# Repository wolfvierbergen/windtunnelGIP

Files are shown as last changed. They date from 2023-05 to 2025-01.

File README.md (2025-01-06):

# Open Wind Tunnel Design and Construction

An experimental project to design, build and test a functional open wind tunnel for aerodynamic testing and research.

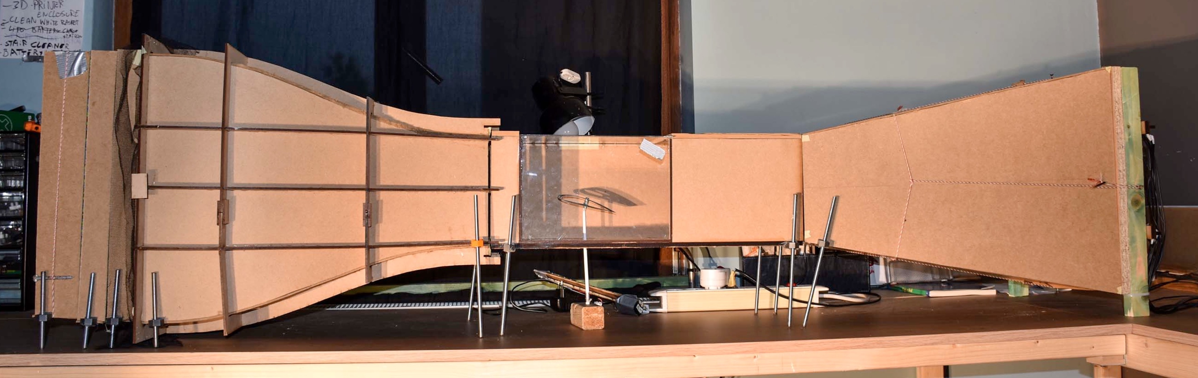
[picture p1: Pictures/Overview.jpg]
Complete Wind Tunnel

*The complete assembled wind tunnel*

**Read the original paper in [dutch](https://github.com/wolfvierbergen/windtunnelGIP/blob/main/eindwerk%20finale%20versie.pdf?raw=true) or the [translated version](https://raw.githubusercontent.com/wolfvierbergen/windtunnelGIP/refs/heads/main/Thesis%20final%20version%20Dutch%20to%20English%20by%20Google%20Translate.pdf)*** <br>
More pictures can be found in the [presentation](https://raw.githubusercontent.com/wolfvierbergen/windtunnelGIP/refs/heads/main/Presentations/Presentatie%20windtunnel%201.2.pdf)<br>

<sub><sup>*Translation is done by Google Translate and contains errors.</sup></sub>
### Key Features

- Open-circuit design with 5.09:1 contraction ratio
- Maximum air speed of 33 km/h (9.2 m/s)
- Laminar flow generation capabilities
- Transparent test section for flow visualization
- Digital speed control system

## Technical Design

The wind tunnel consists of six main components. From left to right:

### 1. Honeycomb Flow Straightener
- 6600 plastic straws arranged in a grid
- 6mm diameter, 60mm length
- Mounted at tunnel inlet
- Reduces **lateral turbulence**

### 2. Flow Conditioning Screens
- Two screens with 64% open area
- Nylon mesh construction
- 45mm spacing between screens
- Reduces **axial turbulence**

### 3. Contraction Section
- 5.09:1 contraction ratio
- Fifth-order polynomial curve profile
- Optimized for minimal flow separation
- MDF construction with external skeleton

### 4. Test Section
- Dimensions: 180mm × 190mm × 580mm
- Plexiglass windows for visualization
- Bottom access port for force measurements

### 5. Diffuser
- 9.9° expansion angle
- 574mm length
- Gradual velocity reduction
- Pressure recovery section

### 6. Drive System
- 4 × 210W brushless motors
- Three-blade propellers
- Electronic speed controllers
- Servo tester for power control
- 7.4V LiPo battery power source

## Experimental Results

### Airfoil Testing
Conducted comprehensive testing using NACA 4412 airfoil:
- Lift coefficient measurements
- Angle of attack comparison
- Speed dependency analysis

Key findings:
1. Maximum lift achieved at 30° angle of attack
2. Experimental results closely matched theoretical predictions

## Technologies Used

- Fusion 360 for CAD design
- Laser cutting for precision components
- 3D printing for custom parts
- Pitot tube airspeed measurement
- Digital force measurement system

## Testing Methods

1. **Air Speed Measurement**
   - Pitot tube system
   - Fluid manometer measurement
   - Multiple test points across section
   - Speed range: 0-33 km/h

2. **Flow Quality Assessment**
   - Smoke visualization
   - Flow uniformity testing

3. **Force Measurement**
   - Digital scale
   - Multiple angle testing

## Contributors

- Maarten Espeel
- Kobe Vlasselaer
- Wolf Vierbergen

## Acknowledgments

Special thanks to:
- Ludo Verluyten (Mentor)
- Bike Valley Team
- Heilig-Hartinstituut Heverlee 

---

**Note**: For detailed technical specifications, experimental procedures, and complete results, please refer to the full thesis document.

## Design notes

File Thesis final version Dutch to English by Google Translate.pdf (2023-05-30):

Sacred Heart Institute
third degree
355 Naamsesteenweg
3001 HEVERLEE

# Wind tunnel

# Design and construction of an open wind tunnel

### Martin Espel

Wolf Vierbergen
Kobe Vlasselaer

### 6 Technology-Sciences

## GIP

School year 2019-2020

Translated from Dutch to English - www.onlinedoctranslator.com (https://www.onlinedoctranslator.com/en/)

Sacred Heart Institute
third degree
355 Naamsesteenweg
3001 HEVERLEE

# Wind tunnel

# Design and construction of an open wind tunnel

### Martin Espel

Wolf Vierbergen
Kobe Vlasselaer

### 6 Technology-Sciences

## GIP

School year 2019-2020
3

4

PREFACE

This integrated test is about designing, building and testing a wind tunnel. This paper was written within the framework of the GIP of 6 TW in the Sacred Heart Institute Heverlee. We worked on this paper from September to April.
Together with our mentor, Ludo Verluyten, we formulated the research questions. Construction was slow in the beginning due to problems with ordering the parts, but it has been nicely finished. In this way we were also able to answer the research question. While writing, we could always ask our mentor, Ludo Verluyten, our questions so that we could continue smoothly.

We would like to thank our mentor for always supporting us in recent months. In addition, our Dutch teacher for improving each version. We would also like to thank Harm Ubbens for his tips and feedback and especially for helping where necessary at the beginning of the research. Without this help, this research would not have been possible.

We would also like to thank all the friends and family who supported us mentally and financially during the design, build, testing and writing of this paper. Thanks to them we can successfully close this investigation.
We wish you a pleasant reading experience.
Kobe Vlasselaer
Martin Espel
Wolf Vierbergen

Leuven, February 2020

5

6

Contents

4
5
6
7

7

INTRODUCTION

Our integrated test (plaster) is about wind tunnels. We absolutely wanted to make our plaster on aerodynamics. We think it is a pity that aerodynamics is not part of the curriculum of secondary education and that is why we wanted to base our plaster on it.
The aim of our plaster is to build a wind tunnel that works so that we can do tests on it. We want to prove that it is possible to generate laminar power with our self-built wind tunnel. It was a long project with many setbacks and additional problems that we did not expect.
Our integrated test also includes an experimental part: we did tests in our wind tunnel and tried to find the optimal angle and shape for a wing so that it experiences as little air resistance as possible.
We looked for our information on the internet and we also visited Bike Valley. They have built a wind tunnel to test the attributes of cycling (kits, shape of bicycle and helmets) so that the cyclist suffers as little as possible from air resistance. There they gave us many tips for the shape and materials of our wind tunnel.

For us it was a very interesting and instructive experience to build a wind tunnel and we hope that you will have an instructive and enjoyable experience reading our integrated test.

8

## 1 literature study

### Aerodynamics

Aerodynamics is the science that describes the movement of gases and liquids. It is part of the field of fluid mechanics. Describing the flow behavior of a liquid or gas can relate to flow in free space or to a body such as an aircraft wing [4].

### History of Aerodynamics

The science of aerodynamics has only existed since the 17th century. Before that, however, people had already used the wind for a long time, such as in a sailing boat and a windmill.

The first person to develop a theory of air resistance was Isaac Newton. He was followed by Daniel Bernoulli, who found a relationship between pressure, density and flow velocity in an incompressible flow. After that, knowledge about aerodynamics progressed at a rapid pace thanks to contributions from Leonhard Euler and Sir George Cayley, among others.

In the early 18th century, Benjamin Robins began measuring air resistance with a whirling arm. Frank H. Wenham also experimented with this, but the results were not satisfactory. This is how the idea of a wind tunnel came about. In 1871 the first wind tunnel was built by the Briton Francis Herbert Wenham, allowing accurate measurements of aerodynamic forces. The experiments he performed were related to lift and drag [17]. A replica of this first wind tunnel can be found in figure 1.

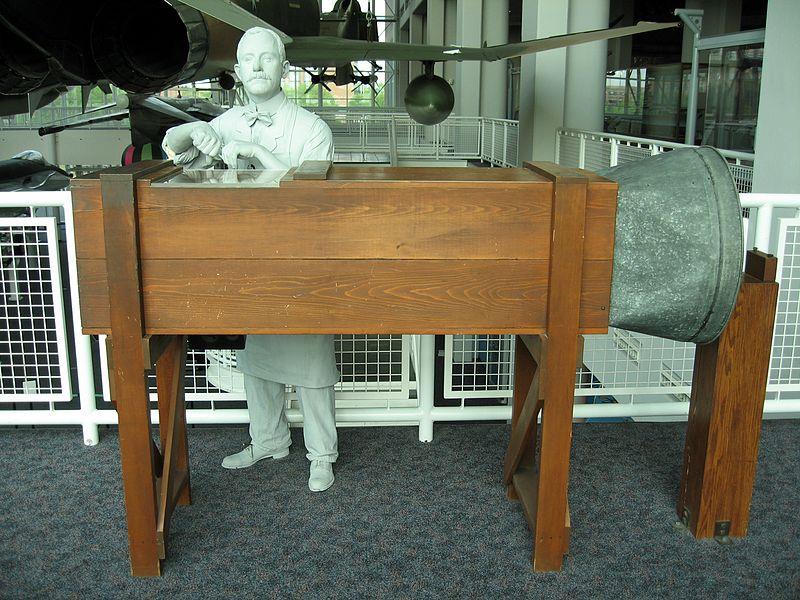
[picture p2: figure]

Figure 1: Replica of the first wind tunnel
German Otto Liliental was the first person to fly in a glider. He succeeded with a new design of the wings, which had a thin and curved airfoil so that they would produce high lift and low drag. Thanks to Liliental's new wings and their own research in their wind tunnel, the Wright brothers made their first successful flight in a powered aircraft on December 17, 1903. [4]

9

### Importance of an aerodynamic object

Air is a matter that exerts a force on an object when it flows past it. During the process, the air sticks to the object a bit, which we call air resistance. For an object that is as aerodynamic as possible, the air resistance must be minimal. The wind therefore sticks a bit on the object, but that does not happen a little above the object. So there is a difference in speed between the air that hits the object (lower airflow) and the air that flows a little above it (upper airflow). This creates a boundary layer between the two different air flows. If the lower airstream separates from the object and collides with the upper airstream, turbulent flow is created. Due to the collision, the wind particles form a swirling trajectory, which causes a lot of air resistance.

In order to obtain an object that is as aerodynamic as possible, it is therefore necessary to ensure that the airflow sticks to the object and does not come loose from it or as little as possible. So one tries to avoid corners and to obtain a nice smooth layer. [19]

### Determination Laminar or turbulent flow

Osbourne Reynolds defined the Reynolds number in 1883. He was an Irish physicist who was mainly concerned with hydraulics and hydrodynamics.
The Reynolds number is a dimensionless quantity used to determine whether a flow is laminar or turbulent. A dimensionless number means that the number has no unit. The number can be calculated using the following formula:

=

Whereby: - =the density in kg/m3• v = the speed in m/s. D = characteristic length in m. µ = the dynamic viscosity expressed in kg/ms

If the Reynolds number has a low value, you have laminar flow, and if the value is high, the flow is turbulent. For example, with flow in tubes you have laminar flow if the Reynolds number has a value below 2300 and you have turbulent flow if the Reynolds number has a value above 3500. If the number has a value between 2300 and 3500, it depends of various factors such as wall roughness whether you have turbulent or laminar flow. [8, 25 & 37]

### Bernoulli's law

Daniel Bernoulli was a Swiss physicist who lived in the 18th century. In 1725 he moved to Saint Petersburg in Russia where he went to study at the newly founded academy. There he met Leonard Euler with whom he would later work closely. Bernoulli's law describes the flow behavior of gases and liquids and gives a

10 explanation of the pressure change with altitude and speed changes. For example, he writes that the faster a gas or liquid passes an object, the lower the pressure on that object will be. Of course, the law also works the other way around, ie the slower a liquid or gas passes through an object, the greater the pressure on that object will be [34, 7]. Bernoulli derived a formula that uses the law of conservation of energy. The sum of the kinetic energy density (dynamic pressure), the gravitational pressure and the pressure equals a constant.

1
2
- 2+ -gh + p = constant

Of - =the density (kg/m3) v = the speed (m/s) g = the acceleration of gravity (m/s2 ) h = the height difference (m) p = the pressure (Pa)

Bernoulli's law applies under a number of conditions. These are the following:
1. Density is constant. The fabric must therefore not be compressed or stretched anywhere.
2. The fabric must not have internal friction. The viscosity should be zero.
3. The flow is stationary (= constant speed).

### Application: Aircraft operation

Like every object on our earth, an airplane is attracted by gravity. In order to put an aircraft in the air, forces that counteract gravity must therefore be exerted. This force, which must ensure that an aircraft does not fall down, is also referred to as 'the lift'. This acting lift force must be greater than gravity and in the opposite direction.

In addition, an aircraft must be able to move in the air. Here too, the aircraft encounters an opposing force, namely the resistance of the air. In order to move in the air, the aircraft must therefore perform extra work, which is provided by the aircraft's engines.

Figure 2 illustrates the action of the various forces.

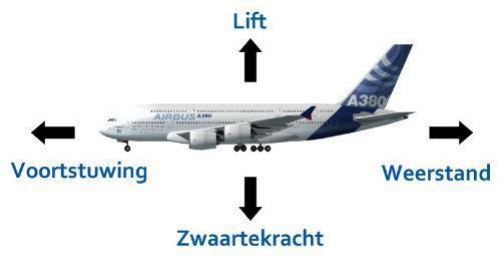
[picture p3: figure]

Figure 2: Forces on an aircraft

11

### Propulsion

In order for an aircraft to propel in the air, it must exert forward thrust. There are two types of engines that can produce this thrust, propeller-driven or jet-powered engines.

In a propeller drive, a rotational movement of a propeller or airscrew is caused by a motor. The propeller rotates in the air and this creates a pressure difference at the front and rear of the propeller blades, creating a forward force. This force pushes the plane forward.

In jet propulsion, air is sucked into the front of a jet engine and then compressed by a compressor. The air is mixed with the fuel and when burned creates a large amount of heat. These heated gases will expand strongly at the rear as they leave the engine. The associated pressure differences cause the propulsive force. The propulsive force generated by the engine must be at least as great as the drag force of the air.

### Resistance

When an object moves forward in the air, this object experiences a resistance from the air particles that opposes the forward movement. This aerodynamic force is a force caused by the object's interaction with the air. Air has a certain viscosity and will, as it were, stick to the object. This creates a speed difference between the air above the surface of the object and the air adjacent to the object. This causes a variation in flow. A laminar flow that offers little resistance can turn into a turbulent flow in which the air particles make rotational movements that increase the resistance. In addition, the air particles have a hard time moving along a sharp angle. A void is then created behind the block with turbulent flows that offer a lot of resistance,

Figure 3: turbulent flow at a block [39]

These turbulent flows must be avoided as much as possible because this means that the aircraft will have to develop more power to move forward. To reduce these turbulent flows, it will be necessary to ensure that the aircraft and wings adopt a shape that is more 'aerodynamic'. Among other things, sharp corners on the aircraft must be avoided. Scientists have been able to show that a wing/aircraft that has a teardrop shape will give the best results [19]. With this teardrop shape, the wing is rounded at the front and ends in a point at the back. This way the laminar flow is maintained as shown in figure no. 4. The droplet as shown in figure 4 is the most aerodynamic.

12

Figure 4: Currents along a drop shape (27)

In addition, the air molecules create a frictional force on the aircraft. It has been shown that when the surface of the aircraft is smooth, there is less friction than with a rough surface [19].

Elevator
To obtain lift in an aircraft, the upward force must be greater than the downward gravitational force, because according to Newton's second law, an object can only lift if the sum of all the forces acting on that object produces a net upward force. Several theories have been described to explain aircraft lift and some theories are more accepted than others. It is always important that lift can only be obtained when a fluid such as air is present, causing the wing to collide with the air molecules when the aircraft is moving forward.
In a first theory, Bernoulli's law is applied. The lift is generated by the specific asymmetric curvature of the wing which causes the flow to flow faster on top of the wing than under the wing. Because of the shape of the wing, the airflow will travel a greater distance at the top than at the bottom. This means that the air has to move faster from above over the wing. These airspeed differences are converted into pressure differences via Bernoulli's law. The greater the speed of the air, the lower the pressure (see Figure 5) [21].

Figure 5: Pressure differences on a wing [21]

This means that the air pressure at the bottom of the wing is higher than at the top. These pressure differences therefore provide a vertical lift force upwards. This theory can be found in many textbooks, but this theory is not entirely correct. According to this theory, in order to gain lift, the wing must have an asymmetrical shape in which the air above the wing travels a longer distance than at the bottom of the wing. However, it has been shown that lift can also be created with wings with a symmetrical shape. In addition, planes can sometimes be seen flying upside down in aircraft shows. The air molecules will then become one

13 travel longer distance at the bottom compared to the top. These aircraft also remain suspended in the air and thus receive a lifting force upwards [26]
Another and currently more accepted explanation for lift force is the fact that due to the shape and angle a wing makes, the air will move in a downward direction. Due to Newton's second law, this will create a downward force on the air. This downward force then causes an upward upward force according to Newton's third law (action and reaction). So the wing exerts a downward force on the air and the air therefore exerts an upward force on the wing as shown in Figure 6.

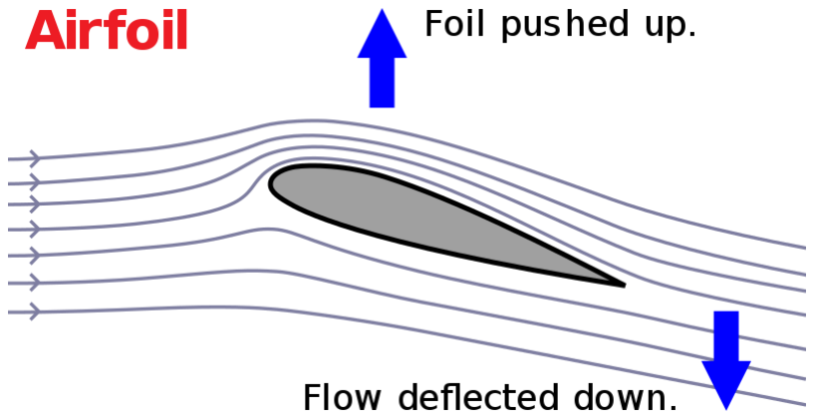
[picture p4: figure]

Figure 6: Downward and upward forces on a wing due to the flow of air [43]
In addition, due to the flow of air under the wing, an overpressure is generated at the underside of the wing compared to the top. These pressure differences then cause a lift force.
In addition, there is also the fact that extra lift can be created by the Coandă effect. When air collides with a surface, it tends to follow the shape of the surface. The forward motion of the aircraft thus creates an airflow that will follow the spherical shape of the wing. This will increase the airspeed and by Bernoulli's law the pressure above the wing will decrease. Which causes extra lift. This effect can be further enhanced by using extra flaps on the wing, as shown in figure 7

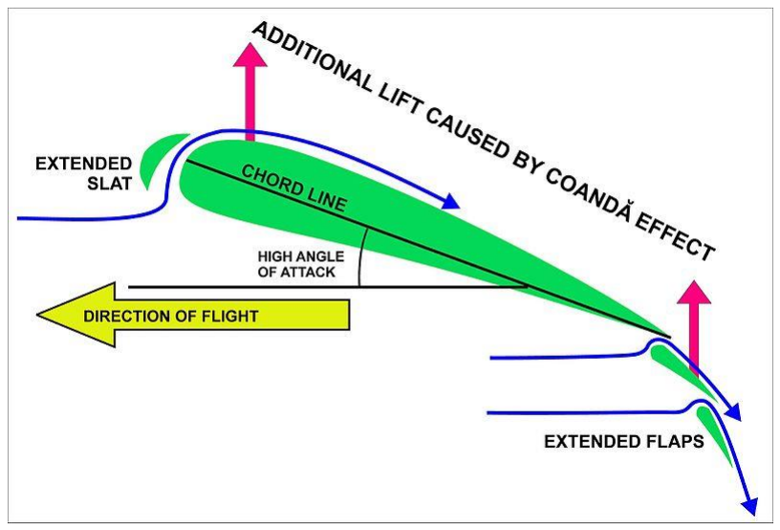
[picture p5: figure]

Figure 7: The Coanda effect on a wing [6])

14

### angle

According to Bernoulli's law, the lift force is determined by the density of the air, the airspeed, the area of the wing and the lift coefficient as shown in the following formula [32]:
=1- × 2× × ( ) 2
Whereby: | L = elevator
- =the density of air in kg/m3
v =airspeed (m/s)
S = area of the wing in m2
CL(-) =lift coefficient relative to the angle of attack - (figure 9)

This lift coefficient is determined by the angle the wing makes with respect to the airflow. This angle is also called the angle of attack. The determination of this angle of attack is shown in figure 8. If the angle of attack is 0°, a lift force is already obtained because the flow of air is already deflected downwards by the asymmetrical shape of the wing. As the angle of attack increases, the lift coefficient increases until it reaches a maximum value. The rise is caused by the ever-increasing speed of the air at the top of the wing and consequently lower pressure opposite the bottom of the wing. The lift coefficient as a function of the angle of attack is shown in Figure 9.

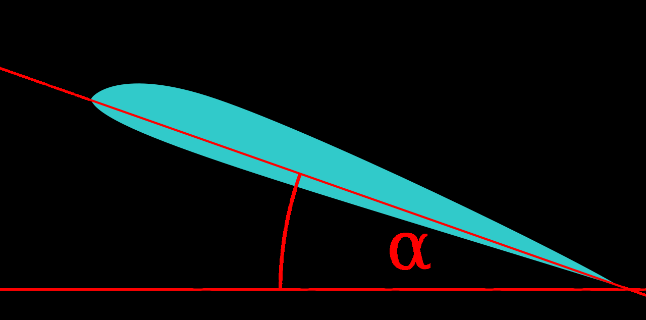
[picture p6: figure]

Figure 8: The angle of view | Figure 9: The lift coefficient as a function of the angle of attack

If the angle of attack is too large (usually around 15°), the airflow at the top of the wing can no longer follow and it will detach from it due to the low pressure. This creates air vortices on top of the wing, negating the upward force (see figure 10) [32]

Figure 8: Flow on a wing at a small angle of attack (left) and at a large angle of attack (right)

15

Determination of the wind speed

A pitot tube is used to measure the wind speed in a wind tunnel. This is a simple measuring device consisting of a simple metal tube in which a few holes are drilled. The first hole is drilled in the front of the tube so that this hole is parallel to the airflow through the wind tunnel. The second and third holes are drilled perpendicular to this in such a way that they are perpendicular to the airflow in the wind tunnel. These holes allow air to enter the pitot tube and make it possible to measure a pressure difference between the air entering the front of the pitot tube and on both sides.

The shafts in the pitot tube perpendicular to the air flow only experience a static pressure (the atmospheric pressure). However, the shaft connected to the hole in the front of the pitot tube experiences both the static atmospheric pressure and an additional dynamic pressure due to the air velocity. The pressure difference that arises between the two shafts can easily be measured by, for example, connecting them on both sides of a tube filled with liquid and measuring the liquid in the U-tube (principle of connected vessels). A schematic representation of the pitot tube is shown in figure 11.

Figure 9: The pitot tube
The difference of the liquid level can later be entered into the Bernoulli equation to measure the air speed.

= +

2 ∗ ( − )

2=
ℎ
Whereby:
- :total pressure
- ∶static pressure (atmospheric pressure)
- :dynamic pressure (pressure due to air speed in wind tunnel)
- :airspeed in wind tunnel
- - : density of the air ℎ
However, an accurate airspeed measurement using a pitot tube requires a sufficiently large airspeed. At very low airspeeds, the errors made on the measurements will become very large [29].

16

Wind tunnel

Definition and principle

A wind tunnel is a useful device for investigating different types of air currents. In a wind tunnel one can thus study the aerodynamic properties of an object. By placing an object in the wind tunnel, you can see the effect of the air on the object and of the object on the airflow. In this way, the object can be adjusted so that it behaves ideally in the air stream.

A wind tunnel, as shown in figure 12, always consists of a funnel in which the air is sucked in and contracted, a straight test section in which the object is placed, and a wider section 'the diffuser' that, through the fans (propellers) present, pushes the air into the tunnel sucks.

Figure 10: Sketch of a wind tunnel [27]
The principle of a wind tunnel is therefore quite simple. The propellers in the rear diffuser rotate to create an airflow in front of the opening of the wind tunnel, in the direction of the wind tunnel. The flow that is sucked in like this is turbulent in nature. This is solved by making a specific funnel structure at the beginning of the wind tunnel in which a
honeycomb is present (see below). This reduces the average surface area and thus increases the speed of the air. Then we come to the test section, the place where the experiments are carried out. After the test section, the average surface area increases again and there is room for fans.

An advantage of using wind tunnels is that experiments can be conducted in a controlled environment, as opposed to exposure to the outside environment. A disadvantage is that scale models often have to be used, since a full-size object is often too large for many wind tunnels [31].

Types of wind tunnels

There are two types of wind tunnels, the open and the closed wind tunnels. Each has its advantages. It is up to us to weigh these against each other. An open wind tunnel is a wind tunnel that does not recirculate the air. The wind tunnel sucks air into the room longest at the front. So passes

17 the air passes through all parts of a wind tunnel and exits the chamber again through the back [10]. The major advantages of an open wind tunnel are that it is simple and more economical to build than a closed wind tunnel. The extra effort and cost are avoided as there are fewer ducts to design and build. The air flow visualization is also easier (smoke can enter longer for easier) and the air temperature rises less quickly. No air purification is required and smoke congestion is avoided. A sketch of an open wind tunnel is shown in Figure 13.

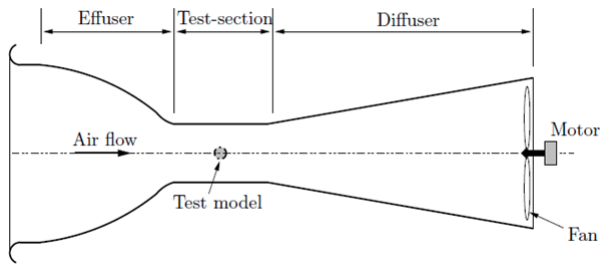
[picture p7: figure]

Figure 11: Open wind tunnel

A closed wind tunnel reuses the same air again. Once driven by the propeller, the air passes through a number of corners, then through the funnel with screens and honeycomb structure. Finally through the test section and the diffuser. In terms of construction, it looks almost the same as an open wind tunnel, with the only visible difference being that the sky follows the same path each time. This entails a number of advantages [5]. Less energy has to be used to obtain a certain air speed and the external factors in the room where the wind tunnel is located (air displacements or dust) have no influence on the air flow. In a closed wind tunnel, the air temperature rises faster. That is why a closed wind tunnel requires an air cooling system, which adds an additional complexity and cost to building it. [10, 5] A sketch of a closed wind tunnel is shown in Figure 14.

Figure 12: closed wind tunnel

Purpose of the project

The goal of this project is that we are able to design and build a wind tunnel ourselves that can generate laminar flow, so that we can perform experiments with results that correspond to those of industrial wind tunnels. In the experimental part of the project we want to find an answer to the following research question: Are we in

18 able to build a wind tunnel in which we can generate laminar flow, which we can then use to perform aerodynamic experiments? To answer this question, we have to divide our main research question into sub-questions:

### 1. What do you need to build a wind tunnel?

### 2. How do you generate laminar flow?

### 3. How can I visualize laminar flow?

### 4. How do you measure airspeed?

### 5. What is the airspeed in the wind tunnel 6. What is the best angle of attack to create lift on a wing?

## 2 Materials and Methods

Requirements and components of an open wind tunnel

To build a functional open wind tunnel that creates laminar flow, the components must meet important requirements. An open wind tunnel consists of 6 major parts: the honeycomb, screens, funnel, test section, diffuser and fans.
To obtain a laminar airflow, 1 honeycomb and 2 screens will be used and a contraction ratio of 5.09:1 will be used. [18]. A contraction ratio is the ratio of the area between the inlet of the wind tunnel and the outlet of the test section.

### Honeycomb

The airflow is made laminar via a honeycomb structure. The cross section of the individual cells of our honeycomb is round. Normally a honeycomb is always hexagonal, but in this document we will always speak of a 'honeycomb'. A honeycomb is a collection of channels that point in the same direction as the airflow. This minimizes cross-flows of the air stream as it enters the wind tunnel.

An optimal ratio of diameter to length of each cell in the honeycomb is 1:10. [36] However, this is what we also strive for. Others claim that a ratio of 1:6 is enough [28]. Of course it doesn't hurt if the cells are longer. We have chosen straws as material for the cells, which are cheap and have an optimal diameter of 0.6 cm. The usable part of the straws (not counting the pliable side) is 18.0 cm long. This 18.0 cm is always cut into 3 parts of 6.0 cm. Thus, the desired ratio of 1:10 has been achieved. Then the shorter straws are placed next to each other and glued together. It is estimated that 2100 straws were used for the honeycomb, so almost 6400 small, individual straws stacked on top of each other and next to each other.
To keep the honeycomb together, 4 panels of 3mm thick MDF are mounted in a square around the honeycomb. The honeycomb is then placed in the beginning of the funnel. In this part of the wind tunnel there is a low wind speed and high pressures, so that the air flow is turbulent.
Since the pressure loss is proportional to the mean speed of the fluid flow, the manipulators are generally installed in the low-speed portion of the wind tunnel. [SCHEIMAN, 1981, page 1]. Translation:Since the pressure drop is proportional to the speed of the liquid flow, the manipulators (in our case the honeycomb and the screens) are generally installed in the low-speed part of the wind tunnel.

19

Images of making the honeycomb structure are shown in Figure 15 and 16.

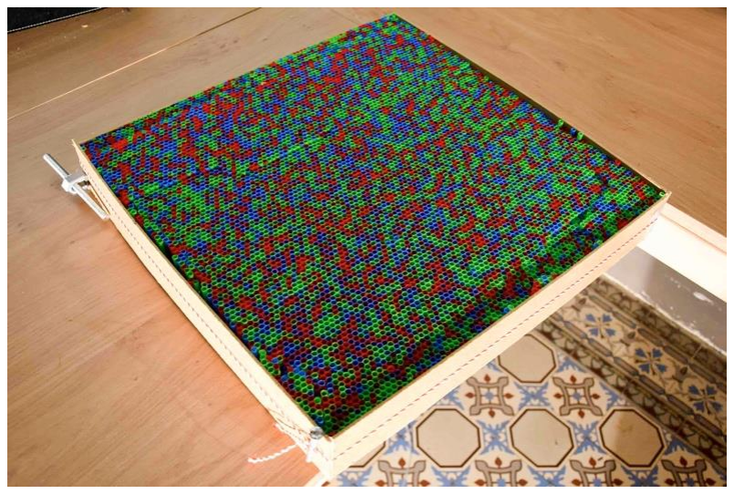
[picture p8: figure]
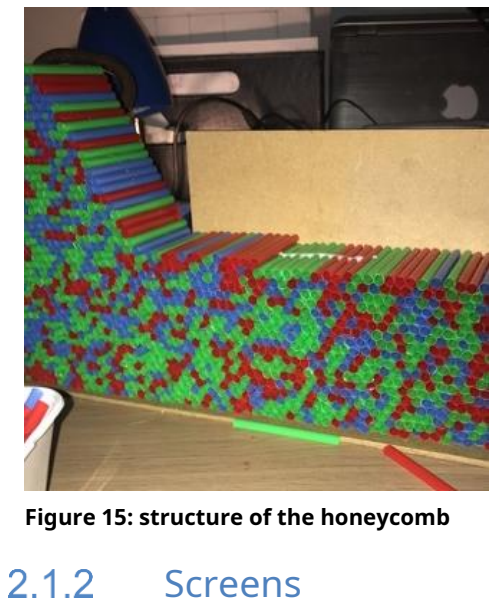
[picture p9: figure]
Screens

Figure 15: structure of the honeycomb | Figure 16: The finished honeycomb

In addition to the honeycomb structure, 'the screens' are also an important part of the funnel to achieve laminar flow. The screens we have chosen are made of mosquito net with a hexagonal shape as shown in figures 17 and 18.

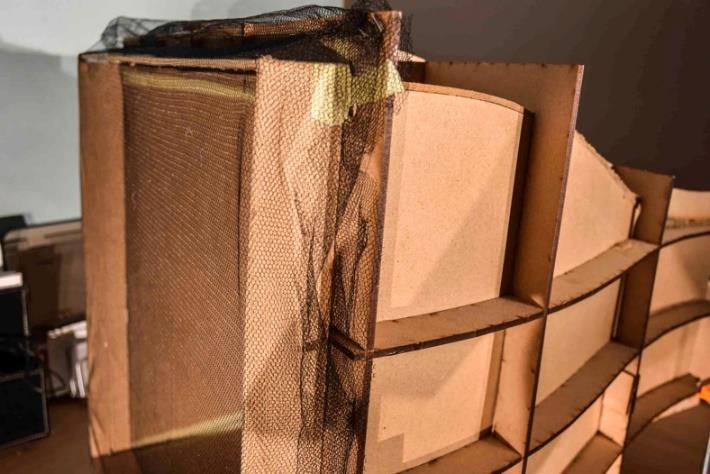
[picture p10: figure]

Figure 17: The funnel with the screens mounted

The screens will ensure that the axial turbulence due to the pressure difference in the cross-section decreases, while the honeycomb will mainly reduce the lateral turbulence [35]. So both constructions are necessary.
To calculate the opening of the mosquito net, we use the following formula [23]:

2× 100
2

= %

20

With the opening size S of 2.0 mm and an intermediate distance C of 2.5 mm (these measurements were made with a digital caliper and are shown in figure 18) we obtain a percentage of 64%.
2.0 2× 100
2.5 2

= 64%

The screen used in the funnel is woven nylon thread and therefore has an opening of 64% (with our measurements).
These openings should not match the openings of the honeycomb. We use two screens in the wind tunnel, the first at 45mm from the honeycomb and the second at 45mm from the first screen. Placing two screens is sufficient for us to achieve the level of turbulence that we want to achieve. [38]

Figure 18: The honeycomb structure of the mosquito net

### The Funnel

The funnel has a specific curved shape.
The shape of this bend is made according to a number of conditions:

### 1. Contraction ratio of 5.09:1. [18] 2. The slats must be able to be cut on a plate that is a maximum of 60.0 cm long and 30.0

cm high (this is the maximum size that fits in the laser cutters).
3. Minimal flow separation (flow separates from a surface).

To make the funnel, 3mm MDF was used for both the skeleton structure and the inside. The skeletal structure was cut out with a laser cutter in the Fablab Leuven at the Arenberg campus III.
To determine the shape of the funnel we use a polynomial of the fifth order (the highest power in 5), proposed by Bell & Metha [30].

= (−10 3+ 15 4− 6 5)( − ) +

Whereby, =

The variables to be determined by us are:

21

1. L, length of the contraction: We chose L 58.0 cm, as the maximum length of a slat is 60.0 cm and we wanted to leave some margin to make the cutting process easier.
2. Hyou, (height of contraction outlet measured from midline). In the original design we have Hyouequal to 10.0 cm, but due to inaccurate bending this has become 9.5 cm.
3. For Hi, (height of the contraction inlet measured from the midline) we chose 22.56 cm.

To achieve a contraction ratio of 5.09:1 we must therefore make Ai 5.09 times larger than Au and the height of the inlet will therefore be 22.56 cm as worked out in the following calculations:

= | : | = ( × 2)2= 400 2
= | : | = × 5.09 = 2036 2

Now we need this surface calculate back to .

| | = ( × 2)2 √
| | 2

=
= 22.56

If we fill all these values into the formula, the graph will look as shown in figure 19.

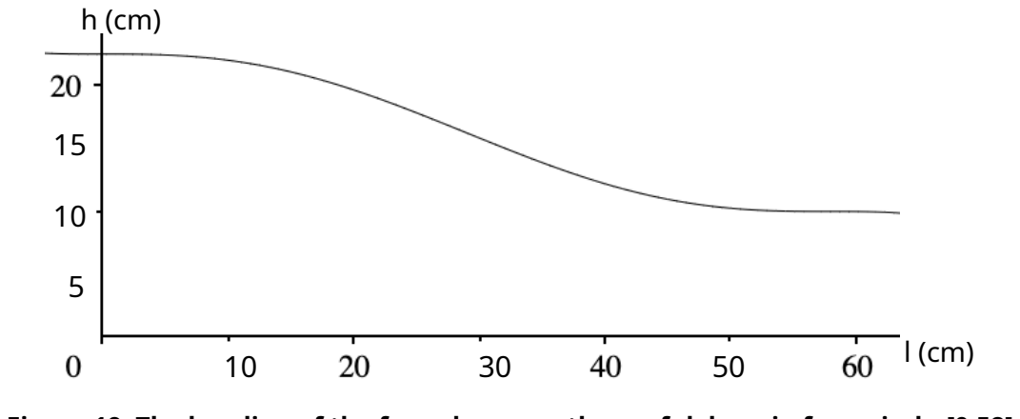
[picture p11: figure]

Figure 19: The bending of the funnel we use, the useful domain for us is: l∈ [0.58]

In this way the shape of the funnel is fixed. The funnel consists of two parts: the skeletal structure and the inner walls. The skeletal structure consists of 3 consecutive square frames. Three slats with a curved shape are attached on all sides in the opening of the frames. So twelve slats in total. This forms the sturdiness of the funnel and the basis for the inner walls. The skeleton structure is shown in figure 20. In this structure, four sheets of 3mm MDF are then bent one by one on each side and glued. To make the plates flexible, they were first moistened with warm water. After this they are placed in the structure and with weights (spread over the surface).

22 bent to the correct shape until the wood has dried. Now the wood is glued to the structure. This happens four times, once for each side. The placement of the inner walls and the use of weights is shown in figure 21. All MDF panels were cut in the FabLab of the Catholic University of Leuven.

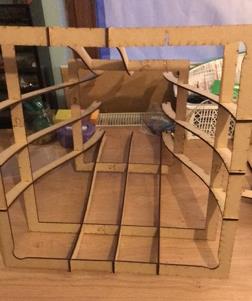
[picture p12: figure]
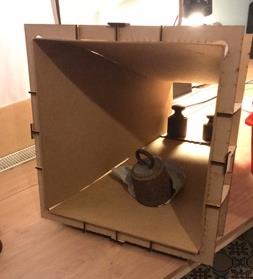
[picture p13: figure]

Figure 20: The skeletal structure | Figure 21: The inner walls that are folded by weights

The finished funnel is shown in Figure 22.

The test section

The testing section is what it's all about. This is where the highest air speed is reached and the tests are therefore also carried out. We aimed for a test section of 20 x 20 cm. Because we had to make adjustments, our test section now measures 19.0 x 18.0 cm and is 58.0 cm long. The length of the wind tunnel is limited by the maximum length of the MDF panels, plus a large cutting margin. The walls are made of 9mm MDF, cut out in the Fablab. We replaced the MDF in the first half, the front and top of the test section

23 through 2mm plexiglass. This allows us, as with many wind tunnels of this size, to look inside and visualize airflow. We also have a 10 mm hole in the bottom in the middle of the visible part of the test section. This allows test equipment to be used and aircraft wings to be directly connected to an external balance. An image of the test section is given in Figure 23.
To maintain accurate results, the test item in the test section should be allowed to flow freely not prevent too much. The rule here is: The cross-sectional area of the test article may not exceed 10% of the cross-sectional area of the test section [28].

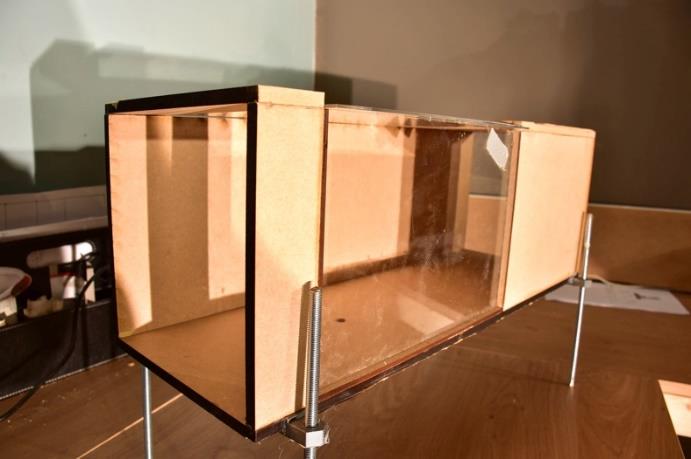
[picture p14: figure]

Figure 23: The finished test section

diffuser

To achieve higher speeds in the test section itself, we placed a diffuser between the test section and the fans. The diffuser also has a funnel shape made of 3 mm MDF plates glued together. Due to the funnel shape, the test section has a smaller diameter than the diffuser and the air pressure in the test section is lower than the air pressure in the diffuser, see Bernoulli's law. As a result, the speed in the test section is higher than the speed in the diffuser. The advantage of this shape is that we can run the fans at a lower speed (rpm), and therefore put less stress on the entire electronic circuit. An image of the diffuser is shown in Figure 24.

24

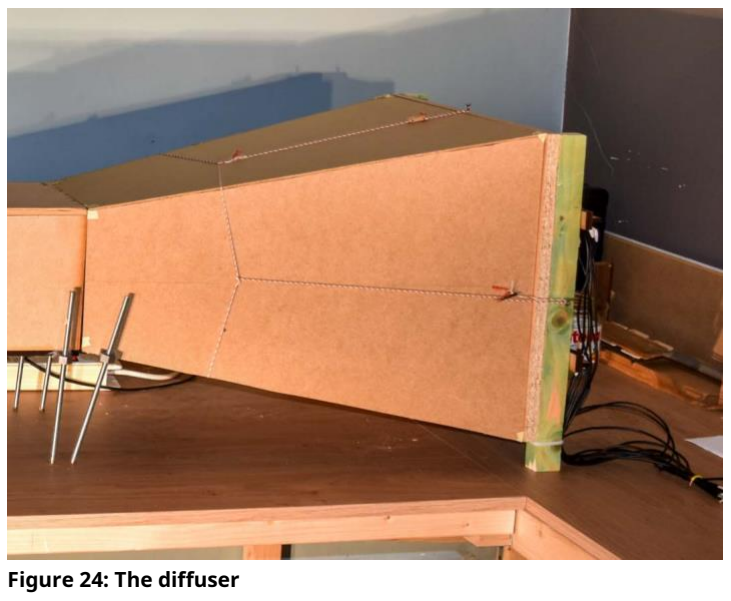
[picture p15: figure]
Figure 24: The diffuser

## Fans

We opted for four fans for an even distribution of the air intake. The 4 fans each consist of a propeller driven by a motor. A schematic representation of the electronic control of the motors is shown in figure 25 and a photograph of all parts of the fans is shown in figure 26.

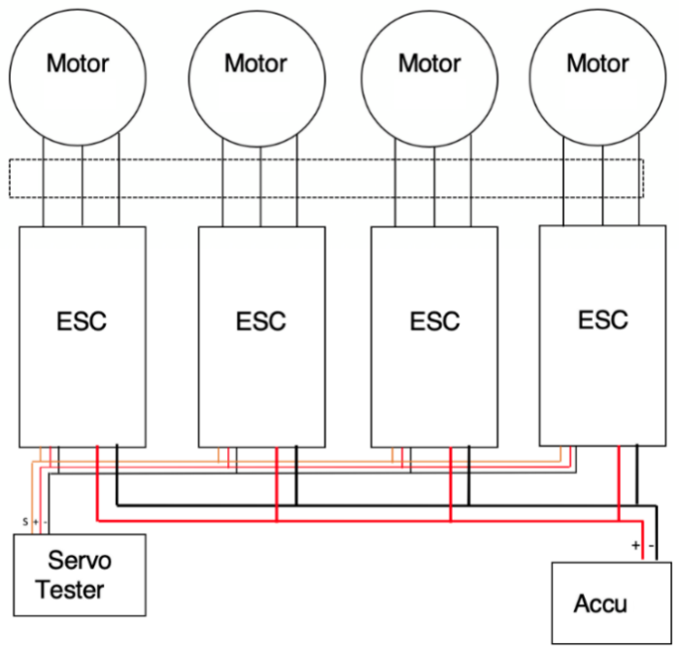
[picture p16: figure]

Figure 25. Schematic overview of the electronic

control of the motors | Figure 26: All parts of the fans.

The fans are made up of a number of different parts with specific requirements:

### 1. We chose 3 blade propellers. For example, the air discharge is better distributed over

the surface of all fans together. The diameter of these propellers is chosen in function of the size of the diffuser opening.

### 2. As a motor we use four brushless motors of the type “Racerstar BR2212 1400KV 2-4S

Brushless Motor For RC-models”. (see table 1)
3. An electronic speed controller, also called ESC (Electronic Speed Controller), is placed on each motor. This ensures that the revolutions per minute (rpm) remain constant.

### 4. The wiring used between the motors and the ESCs are 1.5mm (diameter) with a

flexible PVC housing

### 5. The battery used to power the motors is a LiPo (lithium ion polymer battery)

6000mAh, 7.4V, 60C.
6. A servo tester is required to ensure proper operation of fans. They give a signal to the ESC so that the ESCs know how much power to give from the battery to the motors.

Table 1 shows the specifications at voltage 11.1 V of the propellers we purchased from 'banggood.com website'. However, we have used a voltage of 7.4 V.

25

Tension
(V)

Amperage
(A)

Pull
(g)

Assets
(W)

efficiency

(g/w) Fashion model
BR2212 1400KV | 11.1 | 19.0 | 910 | 210 | 4.3

Table 1: Engine specifications
In table 2 you will find a summary of the components of the fans.

Element
1.
2.
3.
4.
5.
Description Propeller engine Wires ESC Battery | | | Specifications
Diameter: 17.8 cm, 3 leaf, plastic. input voltage = 7.4-14.8V, 210W. Diameter: 1.5 mm, flexible PVC. =30A.
Li-ion polymer battery, 6000mAh, = 360A, U = 7.4V (2 cell). Input: U =
6. | servo tester | 4.2-6.0V.
Table 2: Parts of the fans

The propellers are placed in a laminated OSB board of 430 x430 mm and 15 mm thick with 4 holes cut out of 185.0 mm in diameter. These holes were cut with a milling machine according to the pattern shown in Figure 27. The fans were then soldered together.

Figure 27: The pattern in which the holes are cut.
This plate, in which the propellers are mounted, is connected to the diffuser with a tensioned rope as shown in figure 24.
In summary, the requirements of the different sections of a wind tunnel are shown in Table
3. [18]

Element
1.
2.
3.
4.
5.
6.

Description
Honeycomb
Screens
Funnel
Test section
diffuser
Fan (motors + propellers + electrical circuit)

A = 43.5cm x 43.5cm, 0.6 x 6.0cm 64% open, 138M
CV = 5.09
A = 19.0cm x 18.0cm, L=58.0cm -11°
4x 210W max, 17.8 cm 3 leaf

α =

Table 3: Requirements of the components of a wind tunnel

26

Assembly of the wind tunnel

The funnel, the test section and the diffuser with the propellers are then put together and to support the whole structure we used a system with adjustable uprights. These are made from a threaded rod and a bolt. The bolt is held by a 3D printed part and attached to the different parts of the wind tunnel. The threaded rod was attached below. It adjusts in height by turning the threaded rod. A photograph of the wind tunnel with the legs is shown in Figure 28.

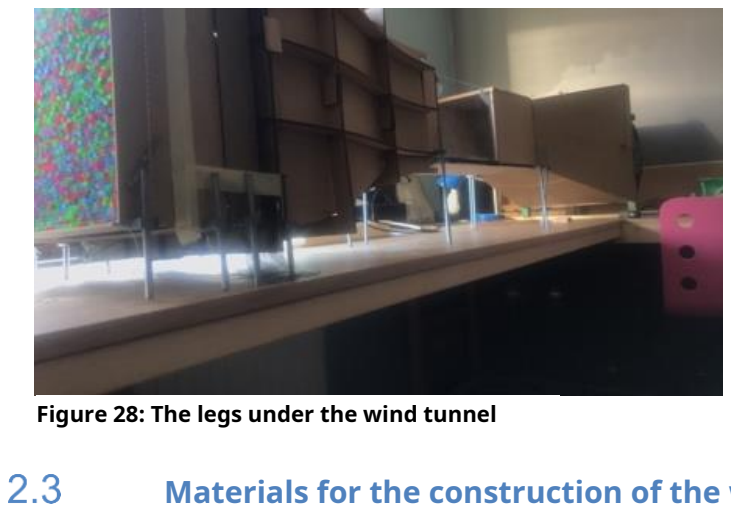
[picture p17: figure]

Figure 28: The legs under the wind tunnel
Materials for the construction of the wind tunnel
- For the design we used a 3D software program 'Fusion 360 (educational license)'
- We used 3mm MDF (Brico) for the funnel wall, the diffuser, the frame of the honeycomb and the intermediate pieces for the mosquito net. These panels are each cut with a pendulum saw. MDF is a soft and light wood that is easy to work with.
- For the funnel skeleton structure we also used 3mm MDF from the FabLab in Leuven. We also cut these in the FabLab with their laser cutters.
- 9mm MDF was used for part of the test section. This way the sides hang better together, without us having to use external support.
- The transparent part of the test section is made of 2mm plexiglass. This was also purchased from the FabLab and cut there with their laser cutters as well.
- The propeller structure is cut out of a laminated OSB board measuring 430 x 430 mm and 15 mm thick.
- The honeycomb structure is mainly made of plastic straws. These are glued together with craft glue and a 3mm MDF frame is placed around all the straws.
- The mosquito net is made of nylon thread woven in such a way that a hexagonal mosquito net is created.

Additional production machines

Various machines and tools are used to make the above mentioned parts. Below is some more technical information.

27

### 1. The laser cutter we used is in the fablab of the brand Trotec Speedy 100R with the

following specifications (610 x 305 mm working space, 132 mm maximum material thickness, 10-120 Watt laser)

### 2. The milling machine used is self-designed and made with inspiration taken from the DIY

3D Printed Dremel CNC” by Nikodem Bartnik. [33]. This milling machine had the following specifications
- 470 x 440 mm working space
- 80 mm material thickness (limited to drill head length).
- 17mm Flat Head Double Flute Spiral Chuck.
- Multi-tool:Dremel 4000.

### 3. The 3D printer (Prusa i3 MK2/S) was used to print the airplane wing and the bolts of

the uprights.
- Cartesian printer
- 250 x 210 x 200mm print volume (XYZ).
- 1.75mm PLA plastic.

### 4. The multi-tool (Dremel 4000, 5000-35000 rpm and 175W): This is used to cut small

things and edit the details. For example, a bit of material protruded somewhere near the funnel and we were able to quickly correct this with the multi-tool. This is also mounted on the milling machine to cut out the propeller structure.
5. The Martin magnum 800 was used as a smoke machine.

## 3 Practical trial

### Wind tunnel design

When designing the wind tunnel, we went through two different versions. The first version was made before we visited BikeValley. During our visit we learned from Harm Ubens that we had to take into account certain elements that were important for the design of the wind tunnel [38]:

1. Harm Ubbens from BikeValley told us that the angles between the funnel and the test section should not be too sharp. If the angle is too sharp, the flow will separate from the wall, generating large pressure differences in the test section.
2. To create a laminar flow, the air speed should be as low as possible. If this happens just before the test section, the air speed will be higher than just before the diffuser. The lower the velocity in the honeycomb structure, the more laminar the flow.
3. It is recommended to use 4 less powerful fans compared to using one fan that would suck in all the air. In addition, the diffuser must have a funnel shape so that the fans have to run less hard.
4. The presence of screens is essential to reduce axial turbulence.
[30]

This is how we came to the development of a second and final version. We avoided sharp corners, installed screens and placed the honeycomb structure in front of the funnel. We also used several fans. The complete wind tunnel setup is shown in Figure 29

28

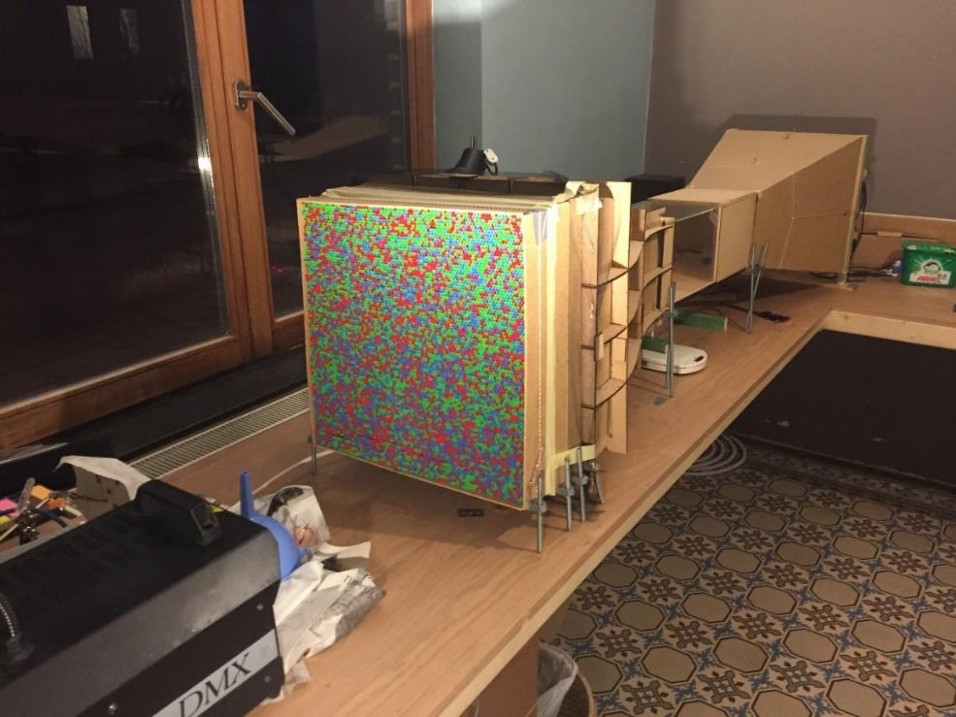
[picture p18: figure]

Figure 29: The general setup of the wind tunnel

### Making laminar flow visible

Once the wind tunnel was assembled, we could start our experimental part. Important here is that we were able to visualize the air flow that we generated in the wind tunnel. For this a smoke machine was used that was placed just before the funnel as shown in figure 29. At maximum speed of the fans we could demonstrate laminar flow as shown in figures 30, 31 and 32. During this process different shapes were used in the test section. placed.

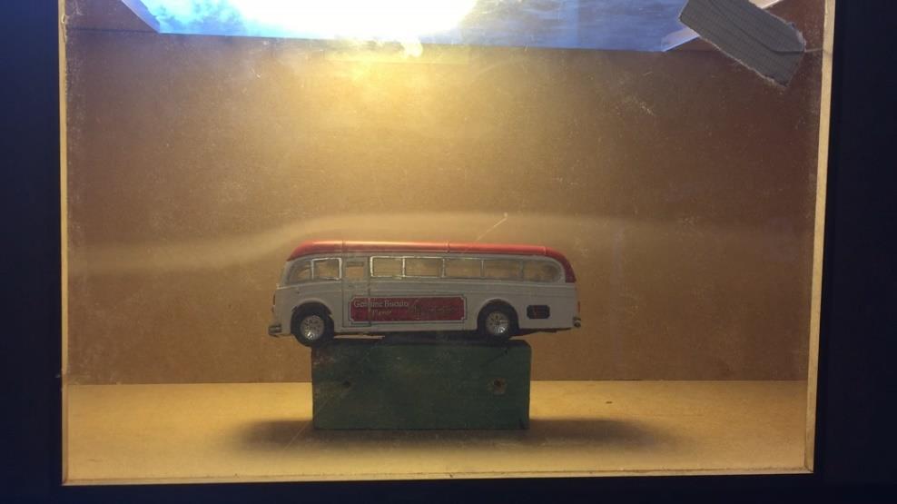
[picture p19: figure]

Figure 30: flow at a bus

29

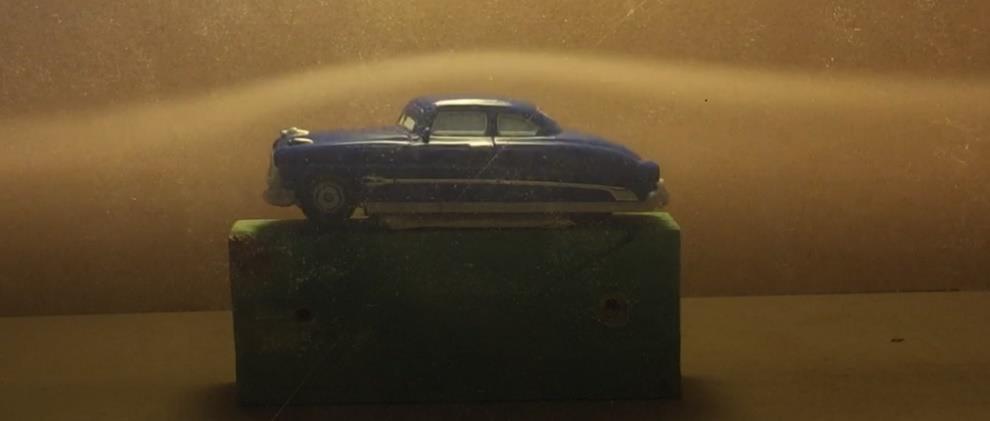
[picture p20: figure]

Figure 31: Current at an old-timer

Figure 32: Current in a racing car

### Determining the airspeed Parts of the test set-up when determining the airspeed

The following materials were used to determine the air speed:

- pitot tube (PT60 tube air speed meter sensor kit differential for pixhawk APM PX4 fight)
- wooden beam to attach pitot tube with bolts
- gin with 40 V% alcohol
- 2 flexible transparent hoses
- U-shaped iron staples
- Wooden board with mm paper stuck on it

To determine the air speed, the pitot tube was screwed onto a wooden beam and connected to flexible hoses filled with gin (40 V% alcohol). The hoses are attached in a U-shape with iron staples to a plate on which mm paper is pasted. The fans are set in different speed positions and the height difference of the liquid is read through the mm paper.

An image of the complete setup is shown in Figure 33.

30

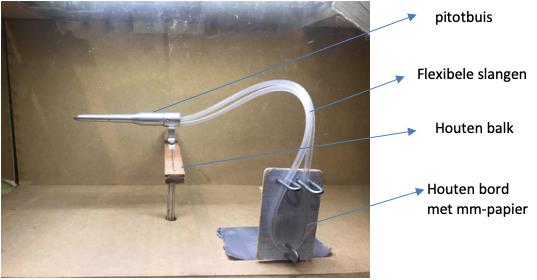
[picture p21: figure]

Figure 33: Illustration of the pitot tube setup in the test section

We had to use a 40% alcohol solution to measure the air speed because measurements could not be made with water. The cohesion between water and the hose was in fact too great to cause a displacement of the water column.

The following formula was used to calculate the speed:

2 . ∆h.ρ .g
v=√
sky
whereby:
-h=height difference
-liquid= density of liquid (930 kg/m3) g= gravitational acceleration (9.81 m/s2) -sky= density of air at 15°C (1.225 kg/m3)

To measure the speed at different places in the test section, the pitot tube is also moved to different points in the cross-section of the test section.

Measurement of the air speed at the maximum position of the fan

The speed of the air was determined at the highest setting of the fan and at various locations in the test section of the wind tunnel.
As shown schematically in Table 4, the wind tunnel was divided imaginatively into nine equal parts. In each case, the pitot tube was placed in the middle of a part of this imaginary section and a measurement was taken at each location. The results of these measurements are shown in Table 5.
Height/ width | Left | Middle | Right
Upstairs | 9 | 3 | 6
Middle | 8 | 2 | 5
below | 7 | 1 | 4

Table 4: Placement of the pitot tube in the test section

At the nine different places in the measurement section, the measured airspeed was very analogous. The airspeed was between 33 and 35 km/h. From this we can conclude that the airflow is homogeneously distributed in the cross-section of the test section.

31

| Δh (mm) | v (m/s) Position | v (in km/h)
1 | 5.5 | 9.1 | 33
2 | 5.6 | 9.1 | 33
3 | 5.2 | 8.8 | 32
4 | 6.1 | 9.5 | 33
5 | 6.0 | 9.5 | 34
6 | 6.1 | 9.5 | 34
7 | 6.2 | 9.6 | 35
8 | 5.6 | 9.1 | 33
9 | 5.8 | 9.3 | 34
Average | 9.3 | 33
Table 5: Determination of homogeneity at maximum fan speed

### Measurement of airspeed at predetermined settings

Subsequently, the air speed at fixed fan settings was measured in the center of the wind tunnel (position 2 in table 4). The results are shown in Table 6. We can demonstrate a linear relationship between air speed and fan speed as shown in Figure 34.

fan-stand | Δh (in mm) | v (in m/s) | v (in km/h)
1 | 0.0 | 0.0 | 0.0
2 | 0.2 | 1.7 | 6.2
3 | 2.0 | 5.5 | 20
4 | 4.0 | 7.7 | 28
5 | 5.7 | 9.2 | 33
Table 6: Determining the air speed at different fan speeds

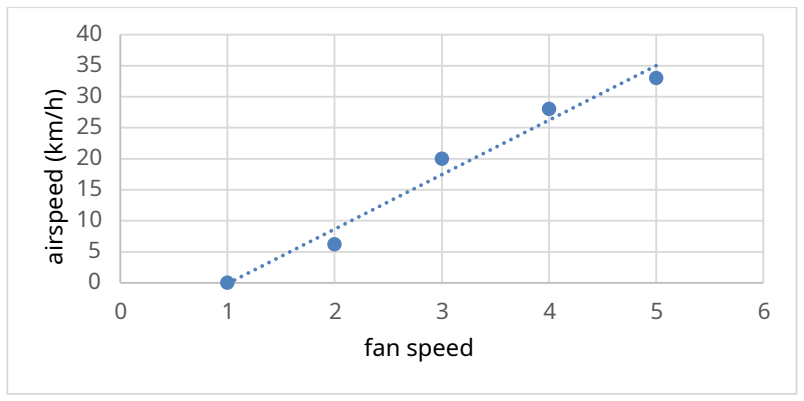
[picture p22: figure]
fan speed; airspeed (km/h)

Figure 14: Relation of air speed to fan speed

32

### Determination of the lift of a wing at different angles of attack

### Method of measuring lift on a wing

The following materials were used to demonstrate the lift of a wing:
- Kitchen scale (Brabantia max 3kg/1g)
- Wooden block with opening
- Metal rod with pliable tip
- 3D printed airplane wing (NACA 4412) (airfoiltools)
- Opening in the bottom of the wind tunnel test section 10mm

To measure the lift of the wing, the 3D printed wing is placed on the tip of a metal bar. The metal rod then goes into the opening of the bottom of the test section. A kitchen scale is placed under the test section of the wind tunnel. A hole is drilled in a wooden block and placed on the scale. The balance is tared to zero. The metal rod with the wing is placed in the drilled hole. The initial mass of the wing is read. Then the fans are started at a specific speed. The mass is now read again. This is repeated at different angles of attack of the wing. The mass difference between the initial value and the final value is then converted into a force (F= -mg).

To prevent the wooden block from coming loose from the scale (and thus incorrect values being measured), it was attached to the scale with adhesive tape at high air velocities.

An image of the wing setup in the test section is shown in Figure 35

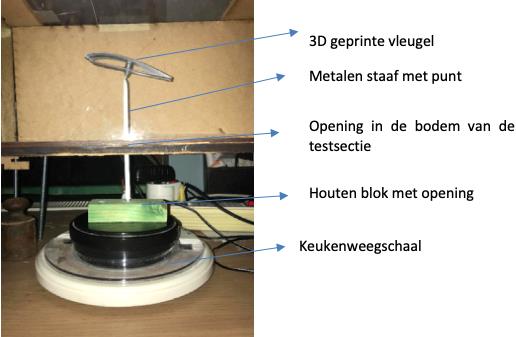
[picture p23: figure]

Figure 35: The arrangement of the wing in the test section
The wing was always placed at a certain angle of attack. The angle of attack was measured as shown in figure 36. A photograph was taken of the wing at a certain angle and the angle to the ground plane was determined with a protractor.

33

Figure 36: Measurement of the angle of attack of the wing
Determination of the lift force and lift coefficient as a function of the angle of attack

At the maximum airspeed of 33 km/h, the lift on the wing was determined at angles of attack in the range of 0° and 60°. The results are shown in Table 7

angle of attack (°) | m (g) | -m (g) | F lift (mN) | Celevator
- 60 | 74 | - 12 | - 12.10 | - 0.52
- 50 | 79 | - 8 | - 78 | - 0.35
- 40 | 80 | - 16 | - 16.10 | - 0.69
- 30 | 78 | - 17 | - 17.10 | - 0.74
- 20 | 69 | - 8 | - 78 | - 0.35
- 10 | 69 | - 6 | - 59 | - 0.26
0 | 49 | 2 | 20 | 0.09
10 | 46 | 9 | 88 | 0.39
20 | 33 | 20 | 20.10 | 0.87
30 | 32 | 31 | 30.10 | 1.3
40 | 34 | 30 | 30.10 | 1.3
50 | 30 | 25 | 25.10 | 1.1
60 | 45 | 10 | 98 | 0.43

Table 7: Determination of lift at different angles of attack
In figure 37 the lift force was plotted as a function of different angles of attack (blue curve). We find that it increases to a critical angle of 30° after which the lift force drops again. The critical angle of attack in our wing is higher than that described in the literature. It is described that a wing loses its lift at an angle of 15° to 20° [11]. So in our experiments this is 10° higher. This variation may be explained by a different way of measuring the angle of attack. At negative angles we notice that the mass of the wing increases and that the wing is pushed against the bottom.
From the experiments, the lift coefficient can also be determined by using the formula of Bernoulli's law:

34

2 .
ℎ . 2.

( ) =
of:

-the density of air (1.225 kg/m3) v the
airspeed (9.3 m/s)
S the area of the wing (43 cm2= 43.10-4m2) cLthe lift
coefficient relative to the angle of attack -

Subsequently, the lift coefficient was also plotted as a function of the angle of attack in Figure 37 (red curve).

Wing lift in function of the angle of attack

Figure 37: Wing lift as a function of the angle of attack
In terms of magnitude, the lift coefficients obtained correspond well with what is reported in the literature for a wing of this type (NACA 4412) (see figure 38) [20]

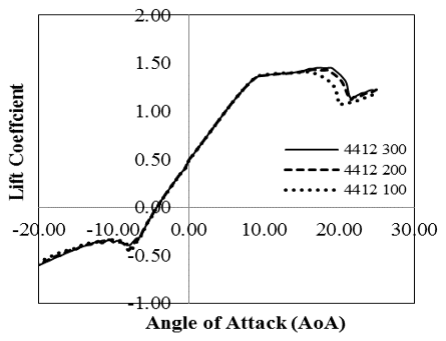
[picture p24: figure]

Figure 38: Calculated and experimental lift coefficient as a function of angle of attack [20]

35

### Lift force and lift coefficient as a function of airspeed

At various airspeeds of Table 6, the lift force on the wing was determined experimentally at a constant angle of attack of 30°. In addition, the theoretical lift force was also calculated using the following formula:

1
2 ℎ | ( ) = . | 2

Whereby::
-the density of air at 15°C (1.225 kg/m3) v the
airspeed (m/s)
S the area of the wing (43.10-4m2)
CLthe lift coefficient relative to the angle of attack - of 30° is 1.3 (see table 7)

The experimental (-mg) and theoretical results are shown in Table 8 and plotted in Figure
39. For our wing, the experimental values are Celevator= 1.34 at 30° angle of attack and the area of the wing is 43 cm2.
| -m (g) | F elevator (mN) (exp) | F lift (mN) (theory) v(m/s)
0.00 | 0 | 0 | 0
1.7 | 2 | 20 | 11
5.5 | 24 | 24.10 | 11.10
7.7 | 29 | 28.10 | 21.10
9.2 | 36 | 35.10 | 30.10
Table 8: Determination of lift at different airspeeds.

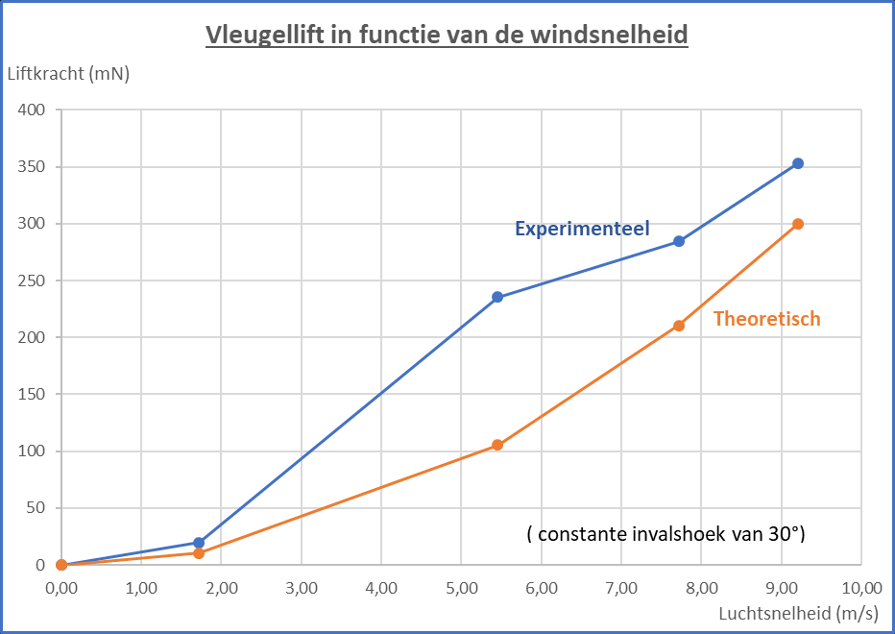
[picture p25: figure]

Figure 39: Wing lift as a function of wind speed

36

If we compare the theoretical curve, which shows a quadratic variation, with the experimental curve, we notice that the experimental curve shows a similar variation except for one deviating point at 5.5 m/s. The reason for this deviation may be due to an inaccurate measurement of the mass of the wing at that speed.

37

## 4 General decision

A wind tunnel is a device that allows a scientist to study the airflow on an object and the additional forces on the object. Originally, a wind tunnel was used to study the aerodynamic properties of an aircraft. Currently, a wind tunnel is used in many disciplines such as the automotive industry, architecture, sports, ...

In this research work, we built an open wind tunnel in which we were able to generate a laminar flow. A wind tunnel always consists of a funnel, a test section and a diffuser in which fans are present. To obtain laminar flow, the funnel into which the air is sucked must meet a number of conditions. There should be a honeycomb consisting of a lot of channels (in our case 6 cm straws) pointing in the same direction as the airflow. In addition, screens are also required to absorb the large pressure differences. These are made of nylon thread woven into a mosquito net. The highest air speed is reached in the test section and the experiments also take place there. Next there is a diffuser. This is also made in the form of a funnel in which 4 fans are placed.

We used a smoke machine to visualize the laminar flow. This smoke machine was placed in front of the funnel so that the smoke was sucked into the wind tunnel. We were able to visualize the air flow around a bus, an old-timer and a racing car. Different wind speeds were obtained via different positions of the fans, which we could measure via a pitot tube. A maximum wind speed of 33 km/h was measured. Subsequently, an aircraft wing of model NACA 4412 was printed using a 3D printer. This wing was used as a test wing to demonstrate lift on the wing. The lift force on a wing was determined at different angles of attack. For example, we were able to demonstrate that the lift force increases to a critical angle of 30°, after which the lift force drops again. This critical angle in our experiments is higher than the 15° angle that we could find in the literature. In addition, the lift coefficient was calculated at different angles of attack. These lift coefficients are in good agreement with the lift coefficients that we could find in the literature for this wing type. As a final experiment, we were able to demonstrate a quadratic relationship between wing lift and wind speed.

38

## 5 Literature list

1) ABUNAN, B.,XFoil predicted lift coefficient for NACA 4412 versus experimental data, internet, (February 9, 2020), (https://www.researchgate.net/figure/XFoil-predicted-liftcoefficient-for-NACA-4412-versus-experimental-data_fig1_309731963). (https://www.researchgate.net/figure/XFoil-predicted-lift-coefficient-for-NACA-4412-versus-experimental-data_fig1_309731963)
2) AIRFOILTOOLS, NACA 4412 airfoil, internet, (nd), (http://airfoiltools.com/airfoil/details?airfoil=naca4412-il)
3) ANOINYEM, Life (force), internet , Wikipedia, January 29, 2020, (https://en.wikipedia.org/wiki/Lift_(force))
4) ANONYMOUS,aerodynamics,internet, Wikipedia, (November 21, 2019), (http://www.woordlijst.eu/betekenis_aerodynamic.htm).
5) ANONYMOUS,Closed return wind tunnel,web, (January 2020), (https://www.grc.nasa.gov/www/k-12/airplane/tuncret.html).
6) ANONYMOUS,Coanda effect, Internet, Wikipedia, December 21, 2019, (https://en.wikipedia.org/wiki/Coand%C4%83_effect) (Figure 5).
7) ANONYMOUS,Daniel Bernoulli, Internet, Wikipedia, (15 January 2020), (https://en.wikipedia.org/wiki/Daniel_Bernoulli).
8) ANONYMOUS,The flow profile, internet, (2020), (https://www.flowmeters.nl/relevantezaken/flowprofile).
9) ANONYMOUS, Laminar Flow, Internet,Wikipedia, November 12, 2019 (https://nl.wikipedia.org/wiki/Laminaire_stroom).
10) ANONYMOUS,open-return wind tunnel,internet, (January 2020), (https://www.grc.nasa.gov/www/k-12/airplane/tunoret.html).
11) ANONYMOUS, Overtrek, Internet, Wikipedia, September 9, 2019, (https://en.wikipedia.org/wiki/Overtrek)
12) ANONYMOUS, Propeller, Internet,Wikipedia, 12 December 2019, (https://nl.wikipedia.org/wiki/Propeller).
13) ANONYMOUS, Jet Engine, Internet,Wikipedia, February 2, 2020, (https://nl.wikipedia.org/wiki/Straalmotor).
14) ANONYMOUS, Turbulent Flow, Internet,Wikipedia,12 November 2019,(https://nl.wikipedia.org/wiki/Turbulent_stroom).
15) ANONYMOUS, Wing (Airplane), Internet,Wikipedia,11 May 2019, (https://nl.wikipedia.org/wiki/Vleugel_(aircraft))
16) ANONYMOUS,Bernoulli's law,unpublished dissertation, 17 pages.
17) ANONYMOUS,Who invented the wind tunnel, web, (February 6, 2020). https://www.centennialofflight.net/wbh/wr_experience/tunnel/testing/ED.htm
18) CELIS, B. and UBBENS, H.,Design and construction of an open-circuit wind tunnel with specific measurement equipment for cycling, unpublished dissertation, Flanders Bike Valley, Paal-Beringen, 2016, 5 pages.
19) CONVENT, MARC-ANTOINE, Flying, art or physics?, internet, (unknown), (http://users.telenet.be/aerodynamica/).
20) Danao, L., A., Abuan, E., Howell, R., Design analysis of a horizontal axis tidal turbine, Conference: Asian Wave and Tidal Conference, 2016
21) DREAMTME, Airplane wing, internet, (nd), (https://www.dreamstime.com/stock-illustration-airplane-wing-cross-section-body-lifting-forces-image48039697)
22) EDITOR AEROLAB,Closed Circuit Wind Tunnels, internet, (unknown), (https://www.aerolab.com/products/closed-circuit-wind-tunnels/).
( | ). (https://www.centennialofflight.net/wbh/wr_experience/tunnel/testing/ED.htm)

39

23) AEROLAB EDITOR,Open Circuit Wind Tunnels, Internet, (unknown), (https://www.aerolab.com/products/open-circuit-wind-tunnels/).
24) EDITOR BOEGER,How to Calculate Perforated Metal Sheet Open Area?internet, (unknown), (https://www.perforated-sheet.com/calculation/how-to-calculate-openarea.html). (https://www.perforated-sheet.com/calculation/how-to-calculate-open-area.html)
25) PHOTO,The Reynolds number, internet, (September 10, 2010), (https://www.modelbouwforum.nl/threads/het-getal-van-reynolds.118439/).
26) HALL, N, NASA Incorrect Theory, Internet, (April 05, 2018), (https://www.grc.nasa.gov/www/k-12/airplane/wrong1.html)
27) HALL, N, NASA Open Return Wind Tunnel , Web, (May 05 2015)
, (https://www.grc.nasa.gov/www/k-12/airplane/tunoret.html)
28) HERNANDEZ, G. and LOPEZ, M.,Design Methodology for a Quick and Low-Cost Wind Tunnel,unpublished dissertation, 2013, 22 pp.
29) KEES,Pitot tube aeronautical and marine,internet, November 19, 2018, (http://zienenweten.blogspot.com/2018/11/pitot-buis-lucht-en-scheepvaart.html).
30) LAKSHMAN, R. and BASAK, R., Analysis of transformed fifth order polynomial curve for the contraction of wind tunnel by using OpenFOAM, unpublished dissertation, National Institute of Technology Sikkim Ravangla Mechanical Engineering, South Sikkim, 2018, 6pp.
31) Lindgren, B; Johansson, AV, Evaluation of the flow quality in the MTL Wind-Tunnel, 2002, Technical reports from royal institute of technology department of mechanics, Stockholm, Sweden.
32) Lindner, B.,The laws of flight,internet, (unknown), (https://www.natuurkunde.nl/artikelen/1762/de-wetten-van-de-vliegkunst).
33) Nikus,DIY 3D Printed Dremel CNC, internet, (unknown), (https://www.instructables.com/id/DIY-3D-Printed-Dremel-CNC/).
34) NTR, (reg.), Who was Daniel Bernoulli, video, Schooltv, Netherlands, 2014.
35) Santos, R., M., an Mesquita, A., L. Development of an open-circuit low-speed wind tunnel, 2015 23rd ABCM International Congress of Mechanical Engineering, December 6-11, Rio de Janeiro
36) SCHEIMAN, J.,Considerations for the Installation of Honeycomb and Screens To Reduce Wind-Tunnel turbulence,unpublished dissertation, Langley Research Center NASA Scientific and Technical Information Branch, Hampton, 1981, 49p.
37) THE EDITORS OF ENCYCLOPAEDIA BRITANNICA,Osborne Reynolds, (August 19, 2019),( https://www.britannica.com/biography/Osborne-Reynolds).
38) UBBENS, H, (Engineer Bike Valley), inform, Bike Valley, Beringen, October 2, 2019.
39) VAN DER VEEN, R. and STEL, B.,How does an airplane fly?internet, (unknown), (https://www.sciencespace.nl/technologie/articles/3900/hoe-vliegt-een-vliegt).

40

## 6 List of figures

Figure 1: Replica of the first wind tunnel | 9
| 11
| 12
| 13
| 13

Figure 2: Forces on an aircraft Figure 3: Turbulent flow at a block Figure 4: Flows
along a teardrop shape Figure 5: Pressure
differences on a wing
Figure 6: Downward and upward forces on a wing due to the flow of air 14
14
15
15

Figure 7: The Coanda effect on a wing Figure
8: The angle of attack
Figure 9: The lift coefficient as a function of the angle of attack
Figure 10: Flow on a wing at a small angle of attack (left) and at a large angle of attack (right)
Figure 11: The pitot tube
Figure 12: Sketch of a wind tunnel
Figure 13: Open wind tunnel
Figure 14: a closed wind tunnel Figure
15: structure of the honeycomb Figure
16: the finished honeycomb
Figure 17: The funnel with the screens mounted Figure
18: The honeycomb structure of the mosquito net
Figure 19: The bending of the funnel we use, the useful domain for us is: l∈ [0.58]

Figure 20: The skeletal structure
Figure 21: The inner walls that are folded by weights Figure 22:
The finished funnel
Figure 23: The finished test section
Figure 24: The diffuser
Figure 25: Schematic overview of the electronic control of the motors Figure 26: All parts of the fans with a bar of 30 cm in front Figure 27: The pattern in which the holes are cut
Figure 28: The legs under the wind tunnel
Figure 29: The general setup of the wind tunnel
Figure 30: Flow near a bus
Figure 31: Current near an old-timer
Figure 32: Current near a racing car
Figure 33: Illustration of the pitot tube arrangement in the test section Figure 34: Relation of airspeed to fan position Figure 35: The wing arrangement in the test section
Figure 36: Measurement of wing angle of attack
Figure 37: Wing lift as a function of angle of attack
Figure 38: Calculated and experimental lift coefficient as a function of angle of attack Figure 39: Wing lift as a function of wind speed

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
## 7 List of tables

Table 1: Motor specifications Table 2:
Fan components
Table 3: Requirements of the components of a wind tunnel
Table 4: Location of the pitot tube in the test section
Table 5: Determination of homogeneity at maximum fan speed Table 6: Determination of air speed at different fan speeds Table 7: Determination of lift at different angles of attack
Table 8. Determination of lift at different airspeeds.

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
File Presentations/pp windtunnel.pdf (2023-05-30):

# Windtunnel

## Ontwerp en constructie van een open windtunnel


Maarten Espeel
Wolf Vierbergen
Kobe Vlasselaer
GIP
2019-2020

Windtunnel

### 2 Constructie

2.1 Rietjes knippen en lijmen


### 2 Constructie


2.2 Ventilatoren • Solderen

### 2 Constructie


2.3 Trechter • | Lasersnijden • | Hout buigen

### 2 Constructie

2.5 Testsectie • | Lasersnijden • | Plexiglas


### 2 Constructie


2.5 Diffuser • Freesmachine

### 3 Praktische proef


3.1 Zichtbaar maken van laminaire stroom

Maximale snelheid
Rookmachine
Specifieke vormen

### 3 Praktische proef

3.2 Bepalen van de luchtsnelheid


v=

2 . ∆h.ρgin.g
ρlucht

Δh=hoogteverschil
ρgin= dichtheid van gin (930 kg/m³ )
g= valversnelling (9,81 m/s²
)
ρlucht= dichtheid van lucht (1,225 kg/m³ )

### 3 Practische proef

3.3 Bepalen van de luchtsnelheid

A. Bij maximale stand van de ventilator
| Links | Midden | Rechts
Boven | 9=34 | 3=32 | 6=34
Midden | 8=33 | 2=33 | 5=34
Onder | 7=35 | 1=33 | 4=34

Gemiddelde: =9,3 m/s of 33 km/u

A. Bij vooraf bepaalde instellingen van de ventilator

ventilator-
stand | v (in m/s) | v (in km/u)
1 | 0.0 | 0.0
2 | 1.7 | 6.2
3 | 5.5 | 20
4 | 7.7 | 28
5 | 9.2 | 33

### 3 Practische proef


3.4 Bepaling van de lift van een vleugel bij verschillende invalshoeken

Vleugel: NACA 4412

### 3 Practische proef

Liftkracht (mN); Invalshoek (°); CLift α =; 2 . FLift; ρLucℎt . v

3.4 Bepaling van de lift van een vleugel bij verschillende invalshoeken

Vleugellift in functie van de invalshoek

Clift
Liftkracht = blauwe curve

Clift= rode curve

( constante luchtsnelheid van 9.3 m/s)

### 3 Praktische proef


3.4 liftkracht en lift coëfficient in functie van de luchtsnelheid

Liftkracht (exp) = blauwe curve

Flift = Δm . g

Flift (theor) = rode curve

FLift =

1
2

. ρLucℎt . v

2
. S . CL α

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
0.00 | 2.00 | 4.00 | 6.00 | 8.00 | 10.00

Liftkracht (mN)

Luchtsnelheid (m/s)

Vleugellift in functie van de windsnelheid

( constante invalshoek van 30°)

Theoretisch

Experimenteel

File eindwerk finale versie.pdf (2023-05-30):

Heilig-Hartinstituut
derde graad
Naamsesteenweg 355
3001 HEVERLEE

# Windtunnel

# Ontwerp en constructie van een open windtunnel

## Maarten Espeel Wolf Vierbergen Kobe Vlasselaer 6 Techniek-Wetenschappen GIP

## Schooljaar 2019-2020

Heilig-Hartinstituut
derde graad
Naamsesteenweg 355
3001 HEVERLEE

# Windtunnel

# Ontwerp en constructie van een open windtunnel

## Maarten Espeel Wolf Vierbergen Kobe Vlasselaer 6 Techniek-Wetenschappen GIP

## Schooljaar 2019-2020

VOORWOORD

Deze geïntegreerde proef gaat over het ontwerpen, bouwen en testen van een windtunnel. Deze paper is geschreven in het kader van de GIP van 6 TW in het Heilig Hart Instituut Heverlee. Van september tot april hebben wij aan deze paper gewerkt.

Samen met onze mentor, Ludo Verluyten, hebben wij de onderzoeksvragen opgesteld. De bouw liep in het begin traag wegens problemen met het bestellen van de onderdelen maar is mooi afgewerkt geraakt. Zo hebben we ook op de onderzoeksvraag kunnen beantwoorden. Tijdens het schrijven konden we aan onze mentor, Ludo Verluyten, altijd onze vragen stellen zodat we vlot verder konden.

Hierbij willen wij graag onze mentor bedanken om ons afgelopen maanden altijd te ondersteunen. Daarnaast onze leerkracht Nederlands voor het verbeteren van elke versie. Ook willen we Harm Ubbens bedanken voor zijn tips en feedback en vooral in het begin van het onderzoek te helpen waar nodig. Zonder deze hulp zou dit onderzoek onmogelijk zijn.

Ook willen wij alle vrienden en familie bedanken die zowel mentaal als financieel hulp boden tijdens het ontwerpen, bouwen, testen en uitschrijven van deze paper. Dankzij hen kunnen we dit onderzoek goed afsluiten.

Wij wensen u een aangename leeservaring toe.

Kobe Vlasselaer
Maarten Espeel
Wolf Vierbergen

Leuven, februari 2020

## Inhoud

INLEIDING

Onze geïntegreerde proef (gip) gaat over windtunnels. Wij wilden absoluut onze gip maken over aerodynamica. We vinden het jammer dat aerodynamica niet tot het studiepakket van het secundaire onderwijs hoort en daardoor wilden we er graag onze gip op baseren.

Het doel van onze gip is om een windtunnel te bouwen die werkt waardoor we er proefjes op kunnen doen. We willen bewijzen dat het mogelijk is laminaire stroom op te wekken met onze zelfgebouwde windtunnel. Het was een lang project met veel tegenslagen en bijkomende problemen die we niet verwacht hadden.
Onze geïntegreerde proef bevat ook een experimenteel gedeelte: we deden proefjes in onze windtunnel en probeerden zo de optimale hoek en vorm te vinden voor een vleugel zodat die zo weinig mogelijk luchtweerstand ondervindt.

Onze informatie hebben we gezocht op het internet en we hebben ook een bezoek gebracht aan Bike Valley. Zij hebben een windtunnel gebouwd om proefjes te doen op de attributen van de wielersport (tenues, vorm fiets en helmen) zodat de wielrenner zo min mogelijk last heeft van luchtweerstand. Daar hebben ze ons veel tips gegeven voor de vorm en materialen van onze windtunnel.

Voor ons was het een zeer boeiende en leerrijke ervaring om een windtunnel te bouwen en we hopen dat u een leerrijke en plezierige ervaring overhoudt aan het lezen van onze geïntegreerde proef.

## 1 literatuurstudie

### Aerodynamica

Aerodynamica is de wetenschap die de beweging van gassen en vloeistoffen beschrijft. Het maakt deel uit van het vakgebied stromingsleer. Het beschrijven van het stromingsgedrag van een vloeistof of gas kan betrekking hebben op stroming in een vrije ruimte of op een lichaam zoals een vleugel van een vliegtuig [4].

### Geschiedenis van de aerodynamica

De wetenschap aerodynamica bestaat pas sinds de 17e eeuw. Daarvoor werd er echter ook al lang gebruik gemaakt van de wind door de mens, zoals bijvoorbeeld bij een zeilboot en een windmolen.
De eerste persoon die een theorie van de luchtweerstand kon ontwikkelen was Isaac Newton. Hij werd gevolgd door Daniel Bernoulli, die een verband vond tussen druk, dichtheid en stromingssnelheid in een onsamendrukbare stroming. Daarna ging de kennis over de aerodynamica in speltempo vooruit dankzij bijdragen van onder andere Leonhard Euler en Sir George Cayley.
In het begin van de 18de eeuw begon Benjamin Robins met luchtweerstand te meten met een 'whirling arm' ('wervelende arm'). Ook Frank H. Wenham experimenteerde hiermee, maar de resultaten hiermee waren niet bevredigend. Zo kwam het idee van een windtunnel. In 1871 werd de eerste windtunnel dan gebouwd door de Brit Francis Herbert Wenham waardoor nauwkeurige metingen van aerodynamisch krachten mogelijk waren. De experimenten die hij uitvoerde waren gerelateerd aan lift en luchtweerstand [17]. Een replica van deze eerste windtunnel kan je terugvinden in figuur 1.


De Duitser Otto Liliental was de eerste mens die een vlucht maakte met een zweefvliegtuig. Dat lukte hem door een nieuw model van de vleugels, ze hadden een dun en gebogen draagvlakte zodat ze een hoge lift en een lage weerstand zouden produceren. Dankzij de nieuwe vleugels van Liliental en eigen onderzoek in hun windtunnel konden de gebroeders Wright voor het eerst een succesvolle vlucht maken met een gemotoriseerd vliegtuig op 17 december 1903. [4]

Figuur 1: Replica van de eerste windtunnel

### Belang van een aerodynamisch voorwerp

Lucht is een materie die op een voorwerp een kracht uitoefent als het erlangs stroomt. Tijdens het proces blijft de lucht een beetje aan het voorwerp kleven, dat noemen we luchtweerstand. Voor een zo aerodynamisch mogelijk voorwerp moet de luchtweerstand minimaal zijn. De wind blijft dus een beetje plakken op het voorwerp maar een beetje boven het voorwerp gebeurt dat niet. Er ontstaat dus een snelheidsverschil tussen de lucht die het voorwerp raakt (onderste luchtstroom) en de lucht die er een beetje boven stroomt (bovenste luchtstroom). Er ontstaat dus een grenslaag tussen de twee verschillende luchtstromen. Als de onderste luchtstroom loskomt van het voorwerp en tegen de bovenste luchtstroom botst, ontstaat er turbulente stroming. De winddeeltjes vormen door de botsing een kolkende baan waardoor er veel luchtweerstand is. Als de onderste luchtstroom niet van het voorwerp loskomt is er geen botsing dus blijft de stroom laminair.
Om een zo aerodynamisch mogelijk voorwerp te bekomen moet men dus zorgen dat de luchtstroom blijft plakken tegen het voorwerp en er niet of zo weinig mogelijk los van komt. Men probeert dus hoeken te vermijden en een mooie gladde laag te bekomen. [19]

### Bepaling Laminaire of turbulente stroming

Osbourne Reynolds definieerde in 1883 het Reynoldsgetal. Hij was een Ierse natuurkundige die zich vooral bezighield met hydraulica en hydrodynamica.
Het Reynoldsgetal is een dimensieloze grootheid dat gebruikt wordt om te bepalen of een stroom laminair of turbulent is. Een dimensieloos getal wil zeggen dat het getal geen eenheid heeft. Het getal kan berekend worden met behulp van de volgende formule:

Waarbij: ρ = de dichtheid in kg/m³ • v = de snelheid in m/s. D = karakteristieke lengte in m. µ = de dynamische viscositeit uitgedrukt in kg/m.s

Als het Reynoldsgetal een lage waarde heeft, heb je laminaire stroom en bij een hoge waarde is de stroom turbulent. Bij stroming in buizen heb je bijvoorbeeld laminaire stroom als het Reynoldsgetal een waarde heeft van onder de 2300 en heb je een turbulente stroming als het Reynoldsgetal een waarde heeft van boven de 3500. Als het getal een waarde tussen de 2300 en 3500 heeft is het afhankelijk van verschillende factoren zoals wandruwheid of je turbulente of laminaire stroom hebt. [8, 25 & 37]

### Wet van Bernoulli

Daniel Bernoulli was een Zwitserse natuurkundige die leefde in de 18de eeuw. In 1725 verhuisde hij naar Sint-Petersburg in Rusland waar hij ging studeren aan de pas opgerichte academie. Daar leerde hij Leonard Euler kennen waarmee hij later nauw mee zou samenwerken. De wet van Bernoulli beschrijft het stromingsgedrag van gassen en vloeistoffen en geeft een

Re =

# ρ. v.D

µ

verklaring aan de drukverandering bij hoogte en snelheidsveranderingen. Zo schrijft hij dat hoe sneller een gas of een vloeistof een voorwerp passeert hoe lager de druk op dat voorwerp zal zijn. Natuurlijk werkt de wet ook omgekeerd, dat wil zeggen dat hoe trager een vloeistof of gas een voorwerp passeert hoe groter de druk op dat voorwerp zal zijn [34, 7]. Bernoulli heeft hierbij een formule afgeleid die gebruik maakt van de wet van behoud van energie. De som van de kinetische energiedichtheid (dynamische druk), de gravitatiedruk en de druk is gelijk aan een constante.

1
2

ρv

2 + ρgh + p = constant

Met ρ = de dichtheid (kg/m³ ) v = de snelheid (m/s) g = de valversnelling (m/s²

)
| h = het hoogteverschil (m) p = de druk (Pa)

De wet van Bernoulli geldt onder een aantal voorwaarden. Deze zijn de volgende:
1. De dichtheid is constant. De stof mag dus nergens samengedrukt of uitgerekt zijn.
2. De stof mag geen inwendige wrijving hebben. De viscositeit moet nul zijn.
3. De stroming is stationair (= constante snelheid).

### Toepassing: Werking van een vliegtuig

Zoals elk voorwerp op onze aarde wordt een vliegtuig aangetrokken door de zwaartekracht. Om een vliegtuig in de lucht te brengen zullen dus krachten moeten inwerken die de zwaartekracht tegenwerken. Deze kracht, die ervoor moet zorgen dat een vliegtuig niet naar beneden valt, wordt ook wel 'de lift' genoemd. Deze inwerkende liftkracht moet groter zijn dan de zwaartekracht en in tegengestelde zin.
Daarnaast moet een vliegtuig kunnen voortbewegen in de lucht. Ook hier ondervindt het vliegtuig een tegenwerkende kracht, namelijk de weerstand van de lucht. Om zich in de lucht te verplaatsen moet het vliegtuig dus extra arbeid verrichten die geleverd wordt door de motoren van het vliegtuig.
In figuur 2 wordt de inwerking van de verschillende krachten geïllustreerd.


Figuur 2: krachten op een vliegtuig

### Voortstuwing

Om een vliegtuig te laten voortbewegen in de lucht moet het een stuwkracht naar voren uitoefenen. Er zijn twee soorten motoren die deze stuwkracht kunnen veroorzaken, namelijk motoren met propelleraandrijving of straalaandrijving.
Bij een propelleraandrijving wordt een draaiende beweging van een propeller of luchtschroef veroorzaakt door een motor. De propeller draait in de lucht en zo ontstaat er een drukverschil aan de voor- en achterzijde van de propellerbladen zodat er een voorwaartse kracht ontstaat. Deze kracht duwt het vliegtuig vooruit.
Bij straalaandrijving wordt lucht aan de voorkant van een straalmotor ingezogen en daarna samengeperst door een compressor. De lucht wordt gemengd met de brandstof en bij verbranding creëert dit een grote hoeveelheid warmte. Deze verwarmde gassen zullen bij het verlaten van de motor aan de achterkant sterk uitzetten. De bijhorende drukverschillen veroorzaken de voortstuwende kracht. De voortstuwende kracht opgewekt door de motor moet minstens even groot zijn als de weerstandskracht van de lucht.

### Weerstand

Wanneer een object voortbeweegt in de lucht ondervindt dit voorwerp een weerstand van de luchtdeeltjes die de voorbeweging tegenwerkt. Deze aerodynamische kracht is een kracht veroorzaakt door interactie van het voorwerp met de lucht. Lucht heeft een bepaalde viscositeit en zal als het ware blijven kleven aan het object. Er ontstaat zo een snelheidsverschil tussen de lucht boven het oppervlak van het voorwerp en de lucht grenzend aan het voorwerp. Dit veroorzaakt een variatie in stroming. Een laminaire stroming die weinig weerstand biedt kan zo omslaan naar een turbulente stroming waarbij de luchtdeeltjes draaiende bewegingen maken die de weerstand verhogen. Bovendien hebben de luchtdeeltjes het moeilijk om langs een scherpe hoek voort te bewegen. Er ontstaat dan achter het blok een leegte met turbulente stromingen die veel weerstand bieden, zoals weergegeven in figuur 3.

Deze turbulente stromingen moeten zo veel mogelijk vermeden worden omdat dit ervoor zorgt dat het vliegtuig meer kracht gaat moeten ontwikkelen om voort te bewegen. Om deze turbulente stromingen te verminderen zal men ervoor moeten zorgen dat het vliegtuig en de vleugels een vorm aannemen die meer 'aerodynamisch' is. Hierbij moet men onder andere scherpe hoeken aan het vliegtuig vermijden. Wetenschappers hebben kunnen aantonen dat een vleugel/vliegtuig die een druppelvorm heeft de beste resultaten zal opleveren [19]. Bij deze druppelvorm is de vleugel vooraan afgerond en eindigt bij achteraan in een spits. Zo blijft de laminaire stroming behouden zoals weergegeven in figuur nr. 4. De druppel zoals weergegeven is figuur 4 is het meest aerodynamisch.

Figuur 3: turbulente stroming bij een blok [39]

Daarbovenop ontstaat er door de luchtmoleculen een wrijvingskracht op het vliegtuig. Men heeft kunnen aantonen dat wanneer het oppervlak van het vliegtuig glad is er minder wrijving optreedt dan bij een ruw oppervlak [19].

### Lift

Om lift bij een vliegtuig te verkrijgen moet de opwaartse kracht groter zijn dan de neerwaartse zwaartekracht, want volgens de tweede wet van Newton kan een voorwerp maar een lift ondergaan als de som van alle krachten die op dat voorwerp inwerken een netto opwaartse kracht oplevert. Er zijn verschillende theorieën beschreven om lift van een vliegtuig te verklaren en sommige theorieën zijn meer aanvaard dan anderen. Belangrijk is steeds dat lift enkel kan verkregen worden, wanneer een fluïdum zoals lucht aanwezig is waardoor, bij voortbeweging van het vliegtuig, de vleugel botst tegen de luchtmoleculen.
In een eerste theorie wordt de wet van Bernoulli toegepast. De opwaartse kracht wordt opgewekt door de specifieke asymmetrische kromming van de vleugel die ervoor zorgt dat de stroming bovenaan de vleugel sneller stroomt dan onder de vleugel. Door de vorm van de vleugel zal de luchtstroom namelijk een grotere afstand afleggen aan de bovenkant dan aan de onderkant. Hierdoor moet de lucht langs boven over de vleugel sneller gaan. Deze luchtsnelheidsverschillen worden via de wet van Bernoulli omgezet in drukverschillen. Hoe groter de snelheid van de lucht is, hoe lager de druk is (zie figuur 5) [21].

Dit betekent dat de druk van de lucht onderaan de vleugel hoger is dan bovenaan. Deze drukverschillen zorgen bijgevolg voor een verticale liftkracht naar boven. Deze theorie vindt men in vele tekstboeken terug, echter deze theorie klopt niet helemaal. Om lift te krijgen moet de vleugel volgens deze theorie een asymmetrische vorm hebben waarbij de lucht bovenaan de vleugel een langere weg aflegt dan onderaan de vleugel. Er is echter aangetoond dat er evenzeer lift kan ontstaan bij vleugels met een symmetrische vorm. Bovendien ziet men in vliegtuigshows soms vliegtuigen ondersteboven vliegen. Hierbij zullen dan de luchtmoleculen een

Figuur 4: stromingen langs een druppelvorm (27)

Figuur 5: Drukverschillen op een vleugel [21]

langere weg afleggen aan de onderkant ten opzichte van de bovenkant. Ook deze vliegtuigen blijven in de lucht hangen en krijgen dus een liftkracht naar boven [26]
Een andere en momenteel meer aanvaarde verklaring voor de liftkracht is het feit dat door de vorm en de hoek die een vleugel maakt, de lucht zal bewegen in een neerwaartse richting. Door de tweede wet van Newton zal er hierdoor een neerwaartse kracht op de lucht ontstaan. Deze neerwaartse kracht veroorzaakt vervolgens volgens de derde wet van Newton (actie en reactie) een opwaartse kracht naar boven. Dus de vleugel oefent een neerwaartse kracht op de lucht en de lucht oefent hierdoor een opwaartse kracht op de vleugel zoals weergegeven in figuur 6.


Figuur 6: Neerwaartse en opwaartse krachten op een vleugel door de stroming van de lucht [43]

Er wordt bovendien door de stroming van de lucht onder de vleugel een overdruk gegenereerd aan de onderkant van de vleugel ten opzichte van de bovenkant. Deze drukverschillen veroorzaken vervolgens een liftkracht.
Daarnaast is er ook sprake van het feit dat er extra lift kan gecreëerd worden door het Coanda-effect. Als lucht botst tegen een oppervlakte dan heeft deze de neiging om de vorm van het oppervlakte te volgen. De voorwaartse beweging van het vliegtuig veroorzaakt zo een luchtstroming die de bolvormige vorm van de vleugel zal volgen. Hierdoor zal de luchtsnelheid verhogen en door de wet van Bernoulli zal de druk verlagen boven de vleugel. Wat extra lift veroorzaakt. Door gebruik te maken van extra flappen aan de vleugel kan men dit effect nog versterken zoals weergegeven in figuur 7

Figuur 7: Het coanda-effect op een vleugel [6])

### Invalshoek

Volgens de wet van Bernoulli wordt de liftkracht bepaald door de dichtheid van de lucht, de luchtsnelheid, de oppervlakte van de vleugel en de liftcoëfficiënt zoals weergegeven in volgende formule [32]:

L =

1
2

ρ × v

## 2 × S × CL(α)

Waarbij: | L = lift ρ = de dichtheid van lucht in kg/m³ v = luchtsnelheid (m/s) S = oppervlakte van de vleugel in m²
| CL(α) = liftcoëfficiënt ten opzichte van de invalshoek α (figuur 9)

Deze liftcoëfficiënt wordt bepaald door de hoek die de vleugel maakt ten opzichte van de luchtstroming. Deze hoek wordt ook de invalshoek genoemd. De bepaling van deze invalshoek wordt weergegeven in figuur 8. Als de invalshoek 0° is krijgt men reeds een liftkracht doordat de stroming van de lucht al naar onder wordt afgebogen door de asymmetrische vorm van de vleugel. Naarmate de invalshoek toeneemt stijgt de liftcoëfficiënt tot deze een maximale waarde bereikt. De stijging wordt veroorzaakt door de steeds toenemende snelheid van de lucht aan de bovenkant van de vleugel en bijgevolg lagere druk tegenover de onderkant van de vleugel. De liftcoëfficiënt in functie van de invalshoek wordt weergegeven in figuur 9.


Bij een te grote invalshoek (gewoonlijk rond de 15°) kan de luchtstroming aan de bovenkant van de vleugel niet meer volgen en komt hij ervan los door de te lage druk. Hierbij ontstaan luchtwervelingen bovenop de vleugel waardoor de opwaartse kracht wordt teniet gedaan (zie figuur 10) [32]

Figuur 8: De invalshoek | Figuur 9: De liftcoëfficiënt in functie van de invalshoek

Figuur 8: Stroming op een vleugel bij kleine invalshoek (links) en bij een grote invalshoek (rechts)

### Bepaling van de windsnelheid

Om de windsnelheid op te meten in een windtunnel wordt er gebruik gemaakt van een pitotbuis. Dit is een eenvoudig meettoestel bestaande uit een simpele metalen buis waarin enkele gaten geboord worden. Het eerste gat wordt geboord in de voorkant van de buis zodat dit gat evenwijdig staat met de luchtstroming doorheen de windtunnel. Het tweede en een derde gat worden hier loodrecht op geboord zodanig dat ze loodrecht staan op de luchtstroming in de windtunnel. Deze gaten laten lucht binnen in de pitotbuis en maken het mogelijk om een drukverschil op te meten tussen de lucht die binnenkomt vooraan de pitotbuis en aan beide zijkanten.
De schachten in de pitotbuis loodrecht op de luchtstroming ondervinden enkel een statische druk (de atmosferische druk). De schacht verbonden aan het gat in de voorkant van de pitotbuis ondervindt echter zowel de statische atmosferische druk als een bijkomende dynamische druk ten gevolge van de luchtsnelheid. Het drukverschil dat ontstaat tussen beide schachten kan eenvoudig opgemeten worden door deze bijvoorbeeld te verbinden aan weerszijden van een buis gevuld met vloeistof en een meting te doen van de vloeistof in de U-buis (principe van verbonden vaten). Een schematische weergave van de pitotbuis is weergegeven in figuur 11.

Het verschil van het vloeistofniveau kan later ingevuld worden in de vergelijking van Bernoulli om op die manier de luchtsnelheid op te meten.

pt = ps + pd

v

2 =

2 ∗ (pt − ps)

ρlucℎt
Waarbij:
- pt
: totale druk
- ps

∶ statische druk (atmosferische druk)
- pd: dynamische druk (druk ten gevolge van luchtsnelheid in windtunnel)
- v : luchtsnelheid in windtunnel
- ρlucℎt

: dichtheid van de lucht

Een accurate meting van de luchtsnelheid met behulp van een pitotbuis vergt echter wel een voldoende grote luchtsnelheid. Bij erg lage luchtsnelheden zullen de fouten gemaakt op de metingen erg groot worden [29].

Figuur 9: De pitotbuis

### Windtunnel

### Definitie en principe

Een windtunnel is een handig apparaat om verschillende types luchtstromingen te onderzoeken. In een windtunnel kan men zo de aerodynamische eigenschappen van een voorwerp bestuderen. Door een voorwerp te plaatsen in de windtunnel ziet men het effect van de lucht op het voorwerp en van het voorwerp op de luchtstroom. Op deze manier kan men het voorwerp aanpassen zodat dit zich ideaal gaat gedragen in de luchtstroom.
Een windtunnel, zoals weergegeven in figuur 12, bestaat steeds uit een trechter waarbinnen de lucht wordt ingezogen en gecontraheerd, een recht testgedeelte waarin het voorwerp geplaatst wordt en een breder deel ‘de diffusor’ die door de aanwezige ventilatoren (propellers) de lucht in de tunnel gaat zuigen.


Het principe van een windtunnel is dus vrij simpel. De propellers in de diffuser achteraan draaien zodat er een luchtstroming gecreëerd wordt voor de opening van de windtunnel, in de richting van de windtunnel. De stroming die zo naar binnen gezogen wordt is turbulent van aard. Dit wordt opgelost door in het begin van windtunnel een specifieke trechterstructuur te maken waarin een honinggraat aanwezig is (zie verder).Hierdoor wordt de doorsneeoppervlakte verkleind en stijgt zo de snelheid van de lucht. Daarna komen we in de testsectie, de plaats waar de experimenten uitgevoerd worden. Na de testsectie vergroot de doorsneeoppervlakte weer en is er plaats voor ventilatoren.

Een voordeel van het gebruik van windtunnels is dat experimenten in een gecontroleerde omgeving kunnen uitgevoerd worden, in tegenstelling tot blootstelling aan de buiten omgeving. Een nadeel is dat vaak schaalmodellen gebruikt moeten worden, aangezien een object op ware grootte vaak te groot is voor veel windtunnels [31].

### Soorten windtunnels

Er zijn twee types windtunnels, de open en de gesloten windtunnels. Elk heeft zijn voordelen. Het is aan ons om deze tegen elkaar af te wegen. Een open windtunnel is een windtunnel dat de lucht niet recirculeert. De windtunnel zuigt langst de voorkant lucht in de kamer. Zo passeert

Figuur 10: Schets van een windtunnel [27]

de lucht langst alle onderdelen van een windtunnel en komt langs de achterkant opnieuw uit de kamer [10]. De grote voordelen van een open windtunnel zijn dat het eenvoudig en economischer te bouwen is dan een gesloten windtunnel. De extra moeite en kosten worden vermeden want er zijn minder kanalen die ontworpen en gebouwd moeten worden. Ook is de luchtstroomvisualisatie gemakkelijker (rook kan langst voor gemakkelijker binnen) en de luchttemperatuur stijgt minder snel. Er is geen zuivering van de lucht nodig en rookopstoppingen worden vermeden. Een schets van een open windtunnel wordt getoond in figuur 13.


Een gesloten windtunnel hergebruikt dezelfde lucht opnieuw. Eenmaal door de propeller aangedreven passeert de lucht door een aantal hoeken, daarna door de trechter met schermen en honinggraatstructuur. Tenslotte door de testsectie en de diffuser. Deze lijkt qua constructie bijna hetzelfde als een open windtunnel, met als enige zichtbare verschil dat de lucht telkens dezelfde weg aflegt. Dit brengt een aantal voordelen met zich mee [5]. Men moet minder energie verbruiken om een bepaalde luchtsnelheid te verkrijgen en de externe factoren in de kamer waar de windtunnel zich bevindt (luchtverplaatsingen of stof) hebben geen invloed op de luchtstroom. In een gesloten windtunnel stijgt de luchttemperatuur sneller. Daarom is er bij een gesloten windtunnel een luchtkoelingssysteem nodig, wat een extra complexiteit en kosten met zich meebrengt bij het maken bouwen ervan. [10, 5] Een schets van een gesloten windtunnel wordt getoond in figuur 14.

### Doel van het project

Het doel van dit project is dat we instaat zijn om zelf een windtunnel te ontwerpen en te bouwen die laminaire stroom kan genereren, zodat we hiermee experimenten kunnen uitvoeren waarvan de resultaten overeenkomen met die van industriële windtunnels. In het experimenteel deel van het project willen we een antwoord vinden op volgende onderzoeksvraag: Zijn wij in

Figuur 11: Open windtunnel

Figuur 12: gesloten windtunnel staat om een windtunnel te bouwen waarin we laminaire stroming kunnen opwekken, die we vervolgens kunnen gebruiken om aerodynamische experimenten uit te voeren? Om op deze vraag te kunnen antwoorden moeten we onze hoofdonderzoeksvraag opdelen in deelvragen:
1. Wat heb je nodig om een windtunnel te bouwen?
2. Hoe wek je laminaire stroming op?
3. Hoe kan ik laminaire stroom zichtbaar maken?
4. Hoe meet je de luchtsnelheid?
5. Wat is de luchtsnelheid in de windtunnel
6. Wat is de beste invalshoek om lift op een vleugel te creëren?

## 2 Materialen en methoden

### Vereisten en onderdelen van een open windtunnel

Om een functionele open windtunnel te bouwen die laminaire stroom creëert moeten de onderdelen voldoen aan belangrijke eisen. Een open windtunnel bestaat uit 6 grote onderdelen: de honinggraat, schermen, trechter, testsectie, diffuser en ventilatoren.
Om een laminaire luchtstroming te verkrijgen zal er gebruik gemaakt worden van 1 honingraat en 2 schermen en zal men een contractieverhouding van 5,09:1 gebruiken. [18]. Een contractieverhouding is de verhouding van de oppervlakte tussen de inlaat van de windtunnel en de uitlaat van de testsectie.

### Honinggraat

De luchtstroom wordt laminair gemaakt via een honinggraatstructuur. De doorsnede van de individuele cellen van onze honinggraat is rond. Normaal is een honinggraat altijd hexagonaal maar in dit document zullen we toch altijd spreken van een 'honinggraat'. Een honinggraat is een verzameling van kanalen die dezelfde richting uitwijzen als de luchtstroom. Zo worden dwarsstromingen van de luchtstroom geminimaliseerd tijdens het binnenstromen van de windtunnel.
Een optimale verhouding tussen diameter en lengte van elke cel in de honinggraat is 1:10.
[36] Dit is echter waar wij ook naar streven. Anderen beweren dat een verhouding 1:6 al genoeg is [28]. Uiteraard kan het geen kwaad als de cellen langer zijn. Als materiaal voor de cellen hebben wij rietjes gekozen, deze zijn goedkoop en hebben een optimale diameter van 0,6 cm. Het bruikbare deel van de rietjes (de plooibare kant niet erbij gerekend) is 18,0 cm lang. Deze 18,0 cm wordt telkens in 3 delen van 6,0 cm geknipt. Zo is de gewenste verhouding van 1:10 bereikt. Vervolgens worden de kortere rietjes naast elkaar gelegd en aan elkaar gelijmd. Er zijn naar schatting 2100 rietjes gebruikt voor de honinggraat, dus bijna 6400 kleine, individuele rietjes op elkaar en naast elkaar gestapeld.
Om de honinggraat bij elkaar te houden zijn er rond de honinggraad 4 panelen van 3mm dik MDF bevestigd in een vierkant. De honinggraat is vervolgen geplaatst in het begin van de trechter. In dit gedeelte van de windtunnel is er namelijk een lage windsnelheid en hoge drukken zodat hierdoor de luchtstroming turbulent is.
Since the pressure loss is proportional to the mean speed of the fluid flow, the manipulators are generally installed in the low-speed portion of the wind tunnel. [SCHEIMAN, 1981, blz 1]. Vertaling: Aangezien het drukverlies evenredig is aan de snelheid van de vloeistofstroom, zijn de manipulatoren (bij ons de honinggraat en de schermen) over het algemeen geïnstalleerd in het lage-snelheidsgedeelte van de windtunnel.

Afbeeldingen van het maken van de honinggraatstructuur zijn weergegeven in figuur 15 en 16.

Schermen

Naast de honinggraatstructuur zijn ‘de schermen’ ook een belangrijk onderdeel van de trechter om laminaire stroom te verkrijgen. De schermen die wij gekozen hebben zijn gemaakt van muggengaas met hexagonale vorm zoals weergegeven in figuur 17 en 18.


De schermen zullen ervoor om te zorgen dat de axiale turbulentie door het drukverschil in de doorsnede, vermindert terwijl het honinggraat vooral de laterale turbulentie zal verminderen [35]. Beide constructies zijn dus nodig.

Om de opening van het muggengaas te berekenen maken we gebruik van volgende formule [23]:

S

2 × 100
C
2 | = %
Figuur 15: opbouw van de honinggraat | Figuur 16: de afgewerkte honinggraat

Figuur 17: De trechter met de schermen gemonteerd

Met de openingsgrootte S van 2.0 mm en een tussenafstand C van 2,5 mm (deze metingen zijn gedaan met een digitale schuifmaat en weergeven in figuur 18) bekomen we een percentage van 64%.

Het gebruikte scherm in de trechter is gewoven nylondraad en heeft dus een opening van 64% (met onze metingen).
Deze openingen moeten niet overeenkomen met de openingen van de honinggraat. We gebruiken in de windtunnel twee schermen, het eerste op 45mm van de honinggraat en het tweede op 45 mm van het eerste scherm. Het plaatsen van twee schermen is voor ons voldoende om het turbulentieniveau dat wij willen halen te bereiken. [38]

### De Trechter

De trechter heeft een specifiek gebogen vorm.
De vorm van deze buiging is gemaakt volgens een aantal voorwaarden:
1. Contractie verhouding van 5.09:1. [18]
2. De latjes moeten uitgesneden kunnen worden op een plaat die maximaal 60.0 cm lang is en 30.0 cm hoog is (dit is de maximale grootte dat in de lasersnijders past).
3. Minimale stroomscheiding (stroom komt los van een oppervlak).

Om de trechter te maken is er gebruik gemaakt van 3mm MDF voor zowel de skeletstructuur als de binnenkant. De skeletstructuur is uitgesneden met een lasersnijder in het Fablab Leuven aan de Arenberg campus III.
Om de vorm van de trechter te bepalen maken we gebruik van een polynoom van de vijfde orde (de hoogste macht in 5), voorgesteld door Bell & Metha [30].

Waarbij, ς =

x
L

De door ons te bepalen variabelen zijn:

2.0 mm² × 100
2.5 mm² = 64%

Figuur 18: De honinggraatstructuur van het muggengaas

y = (−10ς

3 + 15ς

4 − 6ς

5
)(Hi − Hu

) + Hi

1. L, lengte van de contractie: We kozen voor L 58.0 cm, aangezien de maximumlengte van een latje 60.0 cm is en we wilden wat marge laten om het snijproces gemakkelijker te maken.
2. Hu, (hoogte van de contractie uitlaat gemeten vanaf de middellijn). In het oorspronkelijk ontwerp hebben we Hu gelijk aan 10.0 cm gekozen, maar wegens inaccuraat buigen is dit 9.5 cm geworden.
3. Voor Hi, (hoogte van de contractie-inlaat gemeten vanaf de middellijn) kozen we 22.56 cm.

Om een contractieverhouding van 5.09:1 te bereiken moeten we dus Ai 5.09 keer groter maken dan de Au en zal de hoogte van de inlaat dus 22,56 cm zijn zoals uitgewerkt in volgende berekeningen:

Au = oppervlakte uitlaat: | Au = (Hu × 2) 2 = 400 cm²
Ai = oppervlakte inlaat: | Ai = Au × 5.09 = 2036 cm²
Nu moeten we deze oppervlakte Ai | terugrekenen naar Hi .
| Ai = (Hi × 2)
| 2 Hi = √Ai
| 2 Hi = 22,56 cm

Vullen we al deze waardes in de formule, dan ziet de grafiek eruit zoals weergegeven in figuur 19.

Op deze manier is de vorm van de trechter vastgelegd. De trechter bestaat uit twee onderdelen: de skeletstructuur en de binnenwanden. De skeletstructuur bestaat uit 3 opeenvolgende vierkante kaders. In de opening van de kaders zijn langs alle zijden drie latjes met een gebogen vorm bevestigd. Dus twaalf latjes in totaal. Deze vormt de stevigheid van de trechter en de basis voor de binnenwanden. De skeletstructuur is weergegeven in figuur 20. In deze structuur worden vervolgens vier platen van 3mm MDF een voor een op elke zijde gebogen en gelijmd. Om de platen mee buigbaar te maken werden ze eerst bevochtigd met warm water. Hierna worden ze in de structuur gelegd en met gewichten (verspreid over de oppervlakte) in

Figuur 19: De buiging van de trechter die wij gebruiken, het nuttige domein voor ons is: l ∈ [0,58]

de juiste vorm gebogen tot het hout is opgedroogd. Nu wordt het hout aan de structuur vastgelijmd. Dit gebeurt vier keer, een keer voor elke zijde. Het plaatsen van de binnenwanden en het gebruik maken van gewichten is weergegeven in figuur 21. Alle MDF-platen zijn uitgesneden in het FabLab van de Katholieke universiteit Leuven.


De afgewerkte trechter is afgebeeld in figuur 22.

Figuur 22: de afgewerkte trechter

### De testsectie

De testsectie is waar het allemaal om draait. Hierin wordt de hoogste luchtsnelheid bereikt en gebeuren dus ook de proeven. We streefden naar een testsectie van 20 x 20 cm. Omdat we aanpassingen hebben moeten doen meet onze testsectie nu 19,0 x 18,0 cm en is deze 58,0 cm lang. De lengte van de windtunnel is beperkt door de maximumlengte van de MDF platen, plus een ruime snijmarge. De wanden zijn van 9mm MDF gemaakt, uitgesneden in het Fablab. We hebben in de eerste helft, de voorkant en bovenkant van de testsectie, de MDF vervangen

Figuur 20: de skeletstructuur | Figuur 21: De binnenwanden die geplooid worden door gewichtjes

door 2mm plexiglas. Hiermee kunnen we, zoals bij vele windtunnels van dit formaat, binnenkijken en luchtstroom visualiseren. Ook hebben we in het midden van het zichtbare deel van de testsectie een gat van 10 mm in de bodem. Hiermee kan testapparatuur gebruikt worden en kunnen er vliegtuigvleugels direct verbonden worden aan een externe balans. Een afbeelding van de testsectie is gegeven in figuur 23.
Om accurate resultaten te behouden mag het testvoorwerp in de testsectie de luchtstroming niet te veel te verhinderen. Hierbij is de regel: De oppervlakte van de dwarsdoorsnede van het testvoorwerp mag niet groter zijn dan 10% van de oppervlakte van de dwarsdoorsnede van de testsectie [28].


### Diffuser

Om hogere snelheden te behalen in de testsectie zelf hebben we tussen de testsectie en de ventilatoren een diffuser geplaatst. Ook de diffuser heeft een trechtervorm opgebouwd uit 3 mm MDF platen aan elkaar gelijmd. Door de trechtervorm heeft de testsectie een kleinere doorsnede dan de diffuser en is de luchtdruk in de testsectie lager dan de luchtdruk in de diffuser, zie wet van Bernoulli. Hierdoor is de snelheid in de testsectie hoger dan de snelheid in de diffuser. Het voordeel van deze vorm is dat we de ventilatoren op een lagere snelheid (rpm) kunnen laten draaien, en dus ook minder last uitoefenen op het hele elektronische circuit. Een afbeelding van de diffuser is weergegeven in figuur 24.

Figuur 23: De afgewerkte testsectie

Figuur 24: De diffuser

### Ventilatoren

Voor een evenredige verdeling van de luchtaanzuiging hebben we voor vier ventilatoren gekozen. De 4 ventilatoren bestaan elk uit een propeller dat aangedreven is door een motor. Een schematische weergave van de elektronische aansturing van de motoren is weergegeven in figuur 25 en een foto van alle onderdelen van de ventilatoren is weergegeven in figuur 26.


De ventilatoren zijn opgebouwd uit een aantal verschillende onderdelen met specifieke eisen:

1. We hebben gekozen voor propellers met 3 bladen. Zo is de luchtafvoer beter verdeeld over het oppervlak van alle ventilatoren samen. De diameter van deze propellers is gekozen in functie van de grootte van de diffuser-opening.
2. Als motor maken we gebruik van vier borstel loze motoren van het type “Racerstar BR2212 1400KV 2-4S Brushless Motor For RC-models”. (zie tabel 1)
3. Op elke motor wordt een elektronische snelheidsregelaar geplaatst, ook wel ESC genoemd (Electronic Speed Controller). Deze zorgt dat de toeren per minuut (rpm) constant blijft.
4. De bedrading gebruikt tussen de motoren en de ESC’s zijn 1.5 mm (diameter) met een flexibele pvc-behuizing
5. De accu die gebruikt wordt om de motoren aan te drijven is een LiPo (lithium-ion-polymeer-accu) 6000mAh, 7.4V, 60C.
6. Een servo tester is nodig om de goede werking van ventilatoren te garanderen. Ze geven een signaal aan de ESC, zodat de ESC’s weten hoeveel stroom ze moeten geven van de batterij naar de motoren.
Tabel 1 toont de specificaties bij spanning 11,1 V van de propellers die we aangekocht hebben via ‘banggood.com website’. Wij hebben echter een spanning gebruikt van 7,4 V.

Figuur 26: Alle onderdelen van de ventilatoren.

Figuur 25. Schematisch overzicht van de elektronische aansturing van de motoren

Model | Spanning
(V)

Stroomsterkte
(A)

Pull
(g)

Vermogen
(W)

Efficiëntie
(g/w)
BR2212 1400KV | 11.1 | 19.0 | 910 | 210 | 4.3
Tabel 1: Specificaties motoren

In tabel 2 vind je vervolgens een samenvatting van de onderdelen van de ventilatoren.

Onderdeel | Beschrijving | Specificaties
1. | Propeller | Diameter: 17.8 cm, 3 blad, plastic.
2. | Motor | ingangsspanning = 7.4-14.8V, 210W.
3. | Draden | Diameter: 1.5 mm, flexibel PVC.
4. | ESC | Imax = 30 A.
5. | Accu | Li-ion | polymeer | batterij, | 6000mAh,
Imax = 360A, U = 7.4V (2 cel).
6. | Servo tester | Input: U = 4.2-6.0V.
Tabel 2: Onderdelen van de ventilatoren

De propellers worden geplaatst in een gelamineerde OSB-plaat van 430 x430 mm en 15 mm dik waarin 4 gaten zijn uitgesneden van 185,0 mm in diameter. Deze gaten zijn uitgesneden met een freesmachine volgens het patroon weergegeven in figuur 27. De ventilatoren zijn vervolgens aan elkaar gesoldeerd.

Deze plaat waarin de propellers bevestigd zijn, wordt gekoppeld aan de diffuser met een gespannen touw zoals ook te zien is in figuur 24.
Samengevat worden de eisen van de verschillende secties van een windtunnel weergegeven in tabel 3. [18]
Onderdeel | Beschrijving
1. | Honinggraat | A = 43.5 cm x 43.5 cm, 0.6 x 6.0 cm
2. | Schermen | 64% open, 138M
3. | Trechter | CV = 5.09
4. | Testsectie | A = 19.0 cm x 18.0 cm, L=58.0 cm
5. | Diffuser | α = ±11°
6. Ventilator (motoren + propellers +
| elektrisch circuit) | 4x 210W max, 17.8 cm 3 blad

Tabel 3: vereisten van de onderdelen van een windtunnel

Figure 27: Het patroon waarin de gaten zijn uitgesneden.

### Montage van de windtunnel

De trechter, de testsectie en de diffuser met de propellers worden vervolgens tegen elkaar gezet en om de hele structuur te ondersteunen hebben we gebruik gemaakt van een systeem met verstelbare staanders. Deze zijn gemaakt van een draadstang en een bout. De bout wordt vastgehouden door een 3D-geprint onderdeel en bevestigd aan de verschillende delen van de windtunnel. De draadstang werd hieronder bevestigd. Door te draaien aan de draadstang verstelt het zich in hoogte. Een foto van de windtunnel met de poten is weergegeven in figuur 28.

Figure 28: De poten onder de windtunnel

### Materialen voor de bouw van de windtunnel

- Voor het ontwerp hebben we gebruik gemaakt van een 3D-softwareprogramma ‘Fusion 360 (educational licence)’
- Voor de trechter wand, de diffuser, frame van de honinggraat en de tussenstukken voor het muggengaas hebben we 3mm MDF (Brico) gebruikt. Deze panelen zijn telkens met een pendelzaag gesneden. MDF is een zacht en licht hout waarmee gemakkelijk gewerkt kan worden.
- Voor de trechter skeletstructuur hebben we ook 3mm MDF van het FabLab in Leuven gebruikt. We hebben deze ook gesneden in het FabLab met hun lasersnijders.
- Voor een deel van de testsectie is 9mm MDF gebruikt. Zo hangen de zijden beter aan elkaar vast, zonder dat we externe ondersteuning moeten gebruiken.
- Het doorzichtbare deel van de testsectie is gemaakt van 2mm plexiglas. Dit is ook gekocht in het FabLab en ook daar gesneden met hun lasersnijders.
- De propellerstructuur is uitgesneden uit een gelamineerde OSB-plaat van 430 x 430 mm en 15mm dik.
- De honinggraatstructuur is voornamelijk gemaakt van plastic rietjes. Deze worden aan elkaar vastgelijmd met knutsellijm en een kader van 3mm MDF wordt rond alle rietjes geplaatst.
- Het muggengaas is gemaakt van nylondraad zodanig gewoven dat er een hexagonaal muggengaas ontstaat.

### Extra productiemachines

Om de bovenvermelde onderdelen te maken zijn verschillende machines en gereedschap gebruikt. Hieronder volgt wat meer technische informatie.

1. De lasersnijder die we gebruikt hebben staat in het fablab is van het merk Trotec Speedy 100R met volgende specificaties (610 x 305 mm werkruimte, 132 mm maximum materiaaldikte, 10-120 Watt laser)
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

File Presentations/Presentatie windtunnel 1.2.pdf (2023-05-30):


# WINDTUNNEL

Maarten Espeel
Wolf Vierbergen
Kobe Vlasselaer

Mentor: Ludo Verluyten

GIP
2019-2020

## Inhoud

1. Onderzoeksvragen
2. Theorie
2.1 Turbulente/laminaire stroming 2.2 Wet van Bernouilli
3. Praktische proef
3.1 Windtunnel
3.2 Experimenten
4. Algemeen besluit
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

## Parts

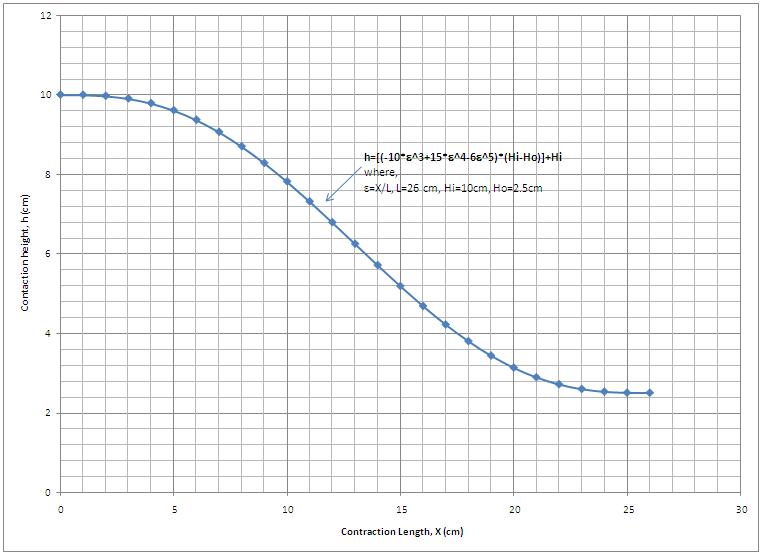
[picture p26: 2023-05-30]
Reference literature/Contraction-cone-is-designed-using-fifth-order-polynomial-principle-recommended-by-Bell.ppm.png

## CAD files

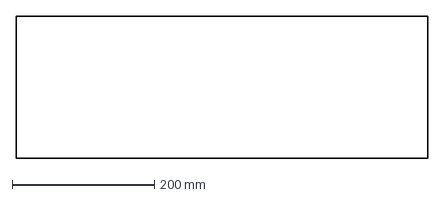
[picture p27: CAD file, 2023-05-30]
manufacturing files/dxf/w.m.backpanel.dxf
580.0 x 200.0 mm

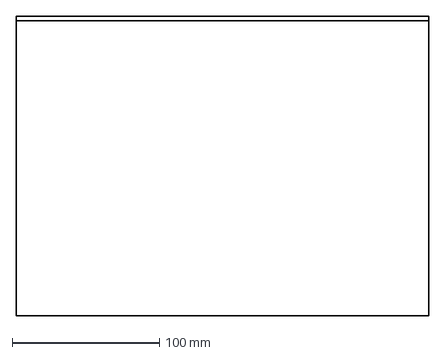
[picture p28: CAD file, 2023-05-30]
manufacturing files/dxf/w.m.plexi.front.dxf
280.0 x 203.0 mm

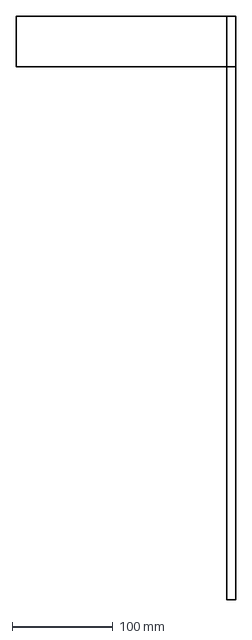
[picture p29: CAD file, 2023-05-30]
manufacturing files/dxf/w.m.small.left.up.dxf
218.0 x 580.0 mm

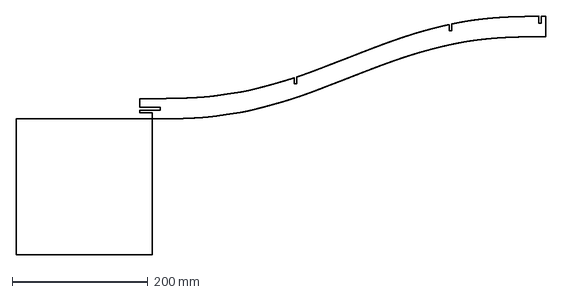
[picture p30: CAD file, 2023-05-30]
manufacturing files/dxf/w.diff.curve.a.dxf
780.0 x 351.0 mm

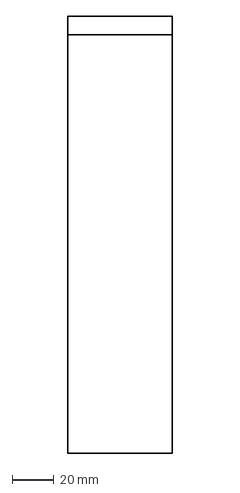
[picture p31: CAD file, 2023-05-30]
manufacturing files/dxf/w.m.small.left.front.dxf
50.0 x 209.0 mm

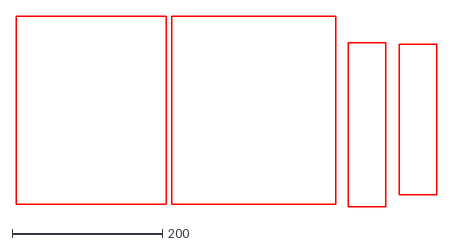
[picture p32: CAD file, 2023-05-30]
manufacturing files/dxf/w.m.big.right.front.dxf
560.0 x 253.3

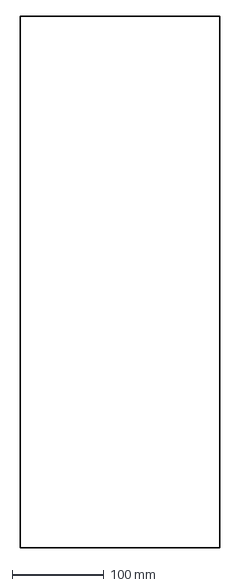
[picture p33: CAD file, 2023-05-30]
manufacturing files/dxf/w.m.groundpanel.dxf
218.0 x 580.0 mm

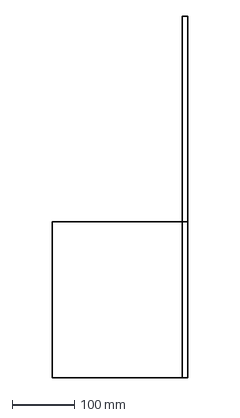
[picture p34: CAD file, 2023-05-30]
manufacturing files/dxf/w.m.big.right.up.dxf
218.0 x 580.0 mm

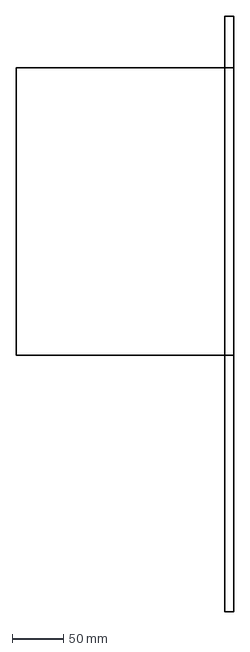
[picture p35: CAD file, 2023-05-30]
manufacturing files/dxf/w.m.plexi.up.dxf
212.0 x 580.0 mm

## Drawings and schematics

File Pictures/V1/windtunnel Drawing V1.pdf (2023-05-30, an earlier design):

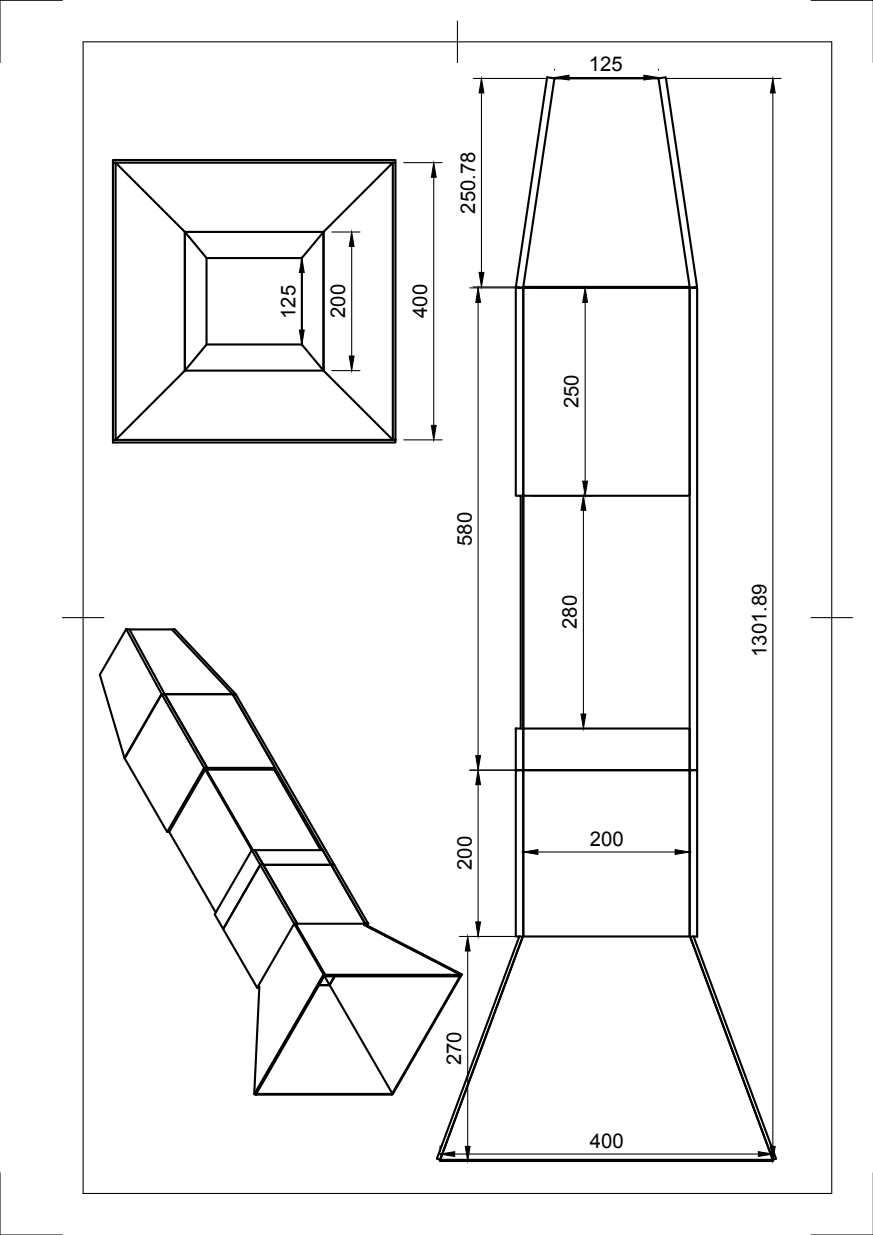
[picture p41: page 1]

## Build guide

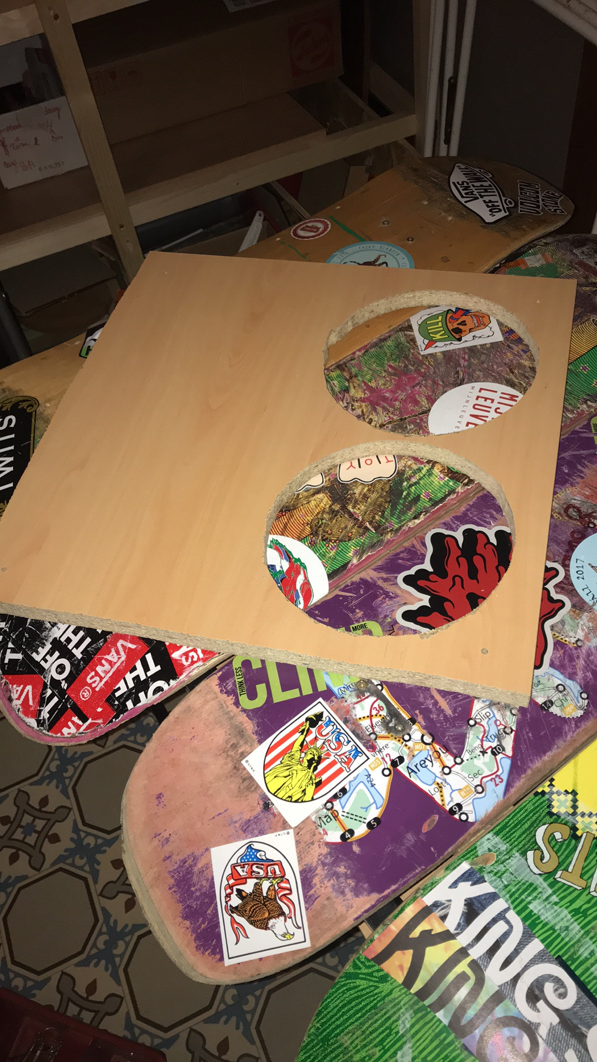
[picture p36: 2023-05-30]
Pictures/V2/Construction/IMG_3356.jpeg

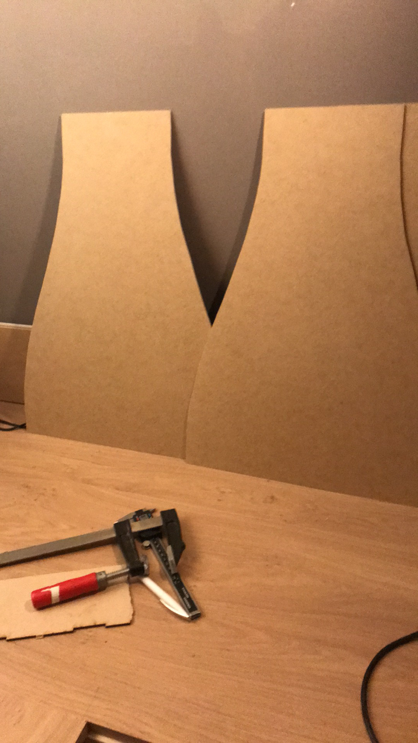
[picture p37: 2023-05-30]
Pictures/V2/Construction/IMG_3484.jpeg

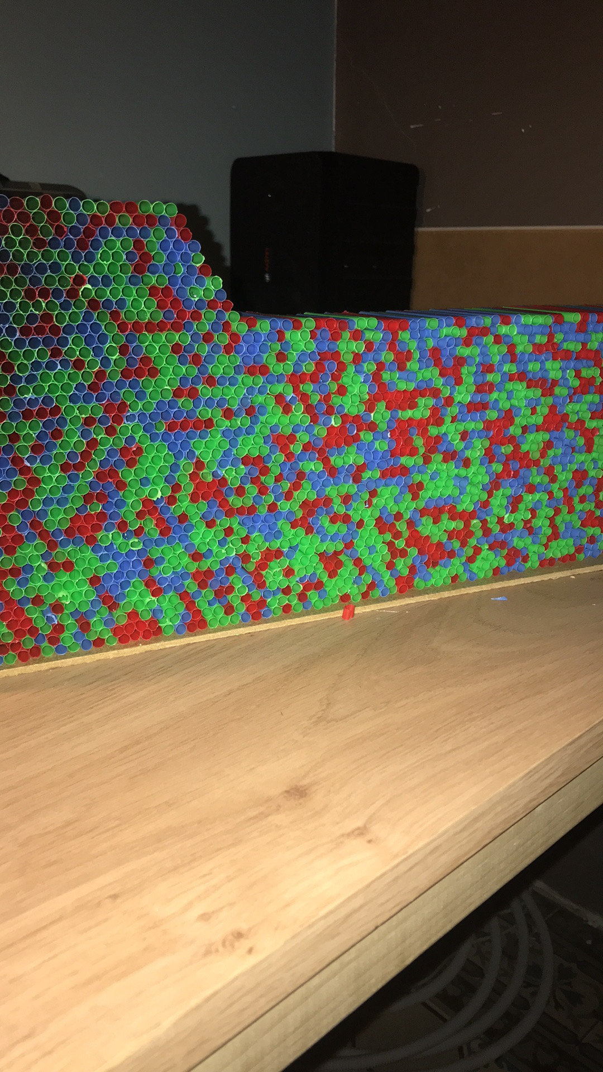
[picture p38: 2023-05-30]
Pictures/V2/Construction/IMG_3577.jpeg

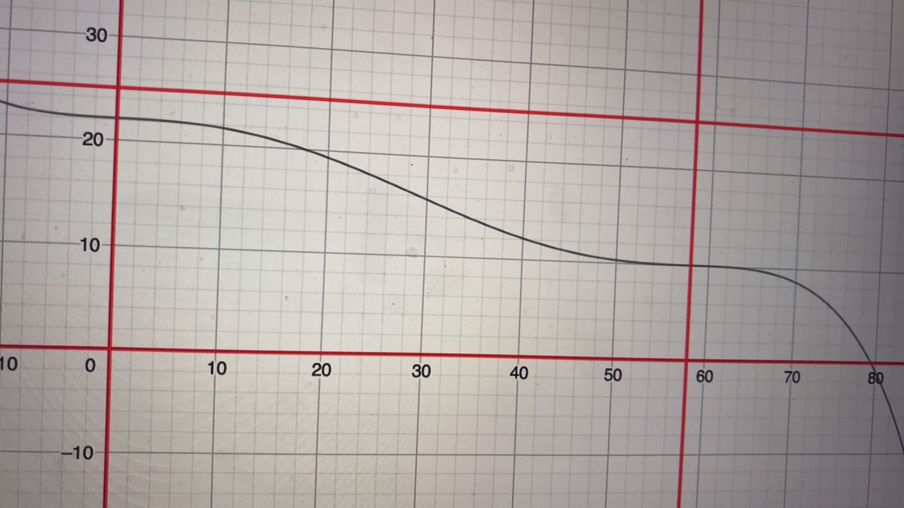
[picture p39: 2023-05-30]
Pictures/V2/Construction/IMG_2867.jpeg

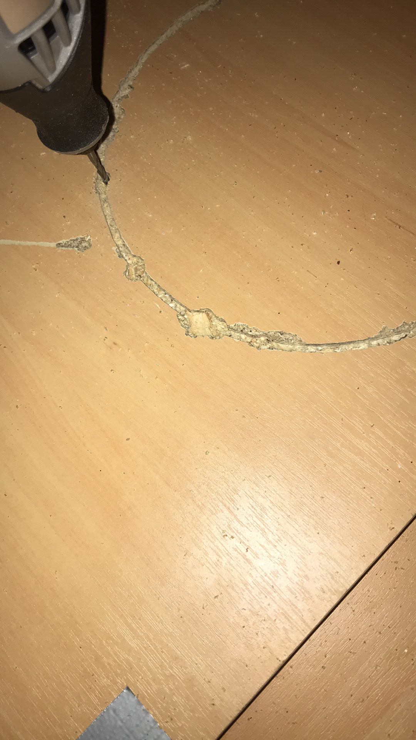
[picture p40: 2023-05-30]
Pictures/V2/Construction/IMG_3355.jpeg
